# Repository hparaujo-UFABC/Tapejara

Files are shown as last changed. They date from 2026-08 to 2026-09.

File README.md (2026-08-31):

# Tapejara
## Open-source quadcopter drone for research and teaching

tapejaraProject03

[Primeiro Voo](https://youtu.be/oPYGQzMy-3I) do Tapejara 1.

🇧🇷
Projeto de um drone quadricóptero como plataforma de ensino e pesquisa.
O projeto da PCB foi realizado com a ferramenta EasyEDA Pro [https://easyeda.com/] e os primeiros protótipos foram fabricados na JLCPCB [https://jlcpcb.com/].
O Tapejara é um minidrone do tipo quadricóptero equipado com uma câmera OV2640 e sensores de IMU, barômetro e magnetômetro. Ele utiliza um microprocessador ESP32 para coletar dados dos sensores, calcular ações de controle e fornecer telemetria.
O drone pode ser controlado remotamente por meio de um aplicativo móvel.
O Tapejara foi projetado para servir como uma plataforma de pesquisa educacional para experimentação com firmware de voo, sistemas de controle e coleta de dados. Por esse motivo, a placa de circuito impresso (PCB) permite expansão via placa filha (*shield*), onde sensores adicionais podem ser instalados.
Vale mencionar que "Tapejara" é um gênero de pterossauro que viveu no Brasil durante o período Cretáceo.

🇺🇸
Design of a quadcopter drone as a teaching and research platform.
The PCB design was created using the EasyEDA Pro tool [https://easyeda.com/], and the initial prototypes were manufactured by JLCPCB [https://jlcpcb.com/].
The Tapejara is a quadcopter-style minidrone equipped with an OV2640 camera and IMU, barometer, and magnetometer sensors. It utilizes an ESP32 microprocessor to collect sensor data, calculate control actions, and provide telemetry.
The drone can be controlled remotely via a mobile app.
The Tapejara was designed to serve as an educational research platform for experimenting with flight firmware, control systems, and data collection. For this reason, the printed circuit board (PCB) allows for expansion via a daughterboard (shield) where additional sensors can be installed.
By the way, "Tapejara" is a genus of pterosaur that lived in Brazil during the Cretaceous period.

## ⚖️ Licença / License

Este é um projeto acadêmico híbrido (Hardware + Software) desenvolvido sob a organização `[Universidade Federal do ABC - UFABC]`. Para incentivar a inovação e facilitar parcerias com a indústria, o projeto utiliza um modelo de licenciamento amigável para uso comercial:

### 🇧🇷 Versão em Português

*   **Hardware (Esquemas, PCBs e Arquivos CAD):** Licenciado sob a [CERN Open Hardware Licence Version 2 – Weak Reciprocal](LICENSE-HARDWARE.md) (**CERN-OHL-W v2**).
    *   *O que isso significa:* Você pode integrar este hardware em produtos comerciais e sistemas proprietários fechados. No entanto, qualquer modificação, melhoria ou correção feita **diretamente nos arquivos de design da nossa placa** deve ser compartilhada publicamente sob a mesma licença.
*   **Software e Firmware:** Licenciado sob a [Apache License 2.0](LICENSE).
    *   *O que isso significa:* O código pode ser usado, modificado e distribuído livremente (inclusive comercialmente), oferecendo proteção explícita de patentes para os desenvolvedores e usuários.

---

### 🇺🇸 English Version

*   **Hardware (Schematics, PCBs, and CAD files):** Licensed under the [CERN Open Hardware Licence Version 2 – Weak Reciprocal](LICENSE-HARDWARE.md) (**CERN-OHL-W v2**).
    *   *What this means:* You are free to integrate this hardware into commercial products and proprietary closed systems. However, any modifications, improvements, or fixes made **directly to our board's design files** must be shared publicly under the same license.
*   **Software and Firmware:** Licensed under the [Apache License 2.0](LICENSE).
    *   *What this means:* The code can be freely used, modified, and distributed (including commercially), providing explicit patent protection for both developers and users.

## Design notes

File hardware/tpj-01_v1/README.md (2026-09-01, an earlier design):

🇧🇷
# Tapejara 1

Primeiro [voo](https://youtu.be/oPYGQzMy-3I) do Tapejara.

Veja a [documentação](./tapejaraBoard_v1.pdf) — Esquemático, layout da PCB e visualização 3D.

[Link](https://oshwlab.com/hparaujo.ufabc/project_sygmsikm?registerLang=en) do projeto no [OSHWLab](https://oshwlab.com/).

> Errata: A pinagem do conector da câmera OV2640 está espelhada: 1 <-> 24 | 24 <-> 1. Não tente conectar a câmera, pois isso causará um curto-circuito na PCB.
> Uma versão corrigida será disponibilizada em uma atualização futura (em breve).
> Todas as outras funcionalidades permanecem inalteradas. O protótipo foi testado em voo por linha de visada.

# Introdução ao projeto

O Tapejara tpj-01 é um micro-drone no estilo quadricóptero equipado com uma câmera OV2640 e sensores IMU, barômetro e magnetômetro. Ele utiliza um microprocessador ESP32 para coletar dados dos sensores, calcular as ações de controle e fornecer telemetria. O drone pode ser controlado remotamente por meio de um aplicativo móvel (atualmente em desenvolvimento).

O tpj-01 foi projetado para servir como uma plataforma de pesquisa educacional para experimentos com firmware de voo, sistemas de controle e coleta de dados. Por esse motivo, a placa de circuito impresso (PCB) permite expansão através de uma placa secundária (shield) onde sensores adicionais podem ser instalados.

A propósito, "Tapejara" é um gênero de pterossauro que viveu no Brasil durante o período Cretáceo.

# Componentes do projeto

* MCU: ESP32-S3 WROOM-1-N16R8
* Câmera OV2640
* IMU: MPU-6050
* Barômetro: BMP280
* Magnetômetro: QMC5883P
* Motores: coreless 7016 / 7020 / 8020 / 8520 (precisa lixar a PCB p/ encaixar o motor) : 2x CW + 2x CCW
* Diâmetro das hélices: 55 / 65 mm (2x CW + 2x CCW)
* Bateria: 1S (3.7V) | 500 mAh
* PCB (X-Frame):
  * Material: FR-4
  * Cor: Verde
  * Espessura: 1.2 mm
* Controle remoto via aplicativo móvel e Wi-Fi

# Descrição do hardware

Este projeto consiste nas seguintes partes:

* O MCU para controle de voo (PID + PWM), coleta de dados dos sensores e telemetria;
* Gerenciamento de energia: a fonte de energia primária do sistema é uma bateria 1S que alimenta os motores diretamente. Um regulador Buck-Boost gera um valor estável de 3.3V para o MCU e os sensores. A câmera também precisa de reguladores LDO para 1.3V e 2.8V, ambos derivados do regulador de 3.3V. A bateria possui proteção contra inversão de polaridade.
* USB/OTG: uma porta micro USB tipo C é usada para upload de firmware e alimentação (durante a programação do drone). Ela possui proteção contra ESD (Descarga Eletrostática).
* PWM: os 4 motores são controlados via sinais PWM gerados no MCU que chaveiam 4 FETs NMOS de potência.
* Sinalização: 4 LEDs podem ser usados para fornecer feedback visual ao usuário. Durante o voo, eles são mantidos acesos para indicação de direção (2 LEDs vermelhos estão posicionados no lado esquerdo do frame e 2 LEDs verdes no lado direito).
* Expansão por Shield: é possível projetar uma placa secundária para expansão de sensores/processamento. A placa principal fornece a tensão da bateria, 3.3V, conexão de aterramento (GND) e 4 pinos de E/S do ESP32 (2 da conexão I²C dos sensores e 2 pinos adicionais).

A própria placa de circuito impresso (PCB) foi projetada em uma configuração em "X" para suportar os motores diretamente, eliminando assim a necessidade de suportes adicionais impressos em 3D. O design é autocontido. A bateria e a câmera devem ser fixadas à placa usando qualquer meio disponível. Para a câmera, existem dois furos na parte frontal do drone que podem ser úteis.

# Processos de montagem

A placa de circuito impresso (PCB) é autocontida. Basta encaixar os quatro motores sob pressão nos devidos lugares (seguindo as marcações impressas na placa) e montar a câmera e a bateria.

O firmware pode ser enviado através da porta USB usando a Arduino IDE. A taxa de transmissão serial (baud rate) é 115200. Para usar a Arduino IDE na programação, selecione esta placa: ESP32-S3-USB-OTG.

Após o upload do firmware, o drone deve ser configurado usando o aplicativo de controle remoto (RC).

# Exibição do produto final

Visualização 3D da PCB (superior e inferior).
3D_Tapejara_brd_v1_Top
3D_Tapejara_brd_v1_Bott

Peso da PCB de apenas 12g.
drone32g

Peso do drone montado de apenas 32.36g.
weightAssembl

Imagem final.
tapejaraAssembled

---

🇺🇸
# Tapejara 1
First [flight](https://youtu.be/oPYGQzMy-3I) of Tapejara.

See the [documentation](./tapejaraBoard_v1.pdf) -- Schematic, PCB layout and 3D view.

Project [Link](https://oshwlab.com/hparaujo.ufabc/project_sygmsikm?registerLang=en) on [OSHWLab](https://oshwlab.com/).

>Errata: The pinout of the OV2640 camera connector is mirrored: 1 &lt;-&gt; 24 | 24 &lt;-&gt; 1. Do not try to connect the camera or it will cause a short-circuit in the PCB.
>A corrected version will be provided in a future update (coming soon).
>All other functionalities remain unchanged. The prototype has been flight-tested via line-of-sight.

# Project introduction
The Tapejara tpj-01 is a quadcopter-style micro-drone equipped with an OV2640 camera and IMU, barometer, and magnetometer sensors. It utilizes an ESP32 microprocessor to collect sensor data, calculate control actions, and provide telemetry.
The drone can be controlled remotely via a mobile app (currently under development).
The tpj-01 was designed to serve as an educational research platform for experimenting with flight firmware, control systems, and data collection. For this reason, the printed circuit board (PCB) allows for expansion via a daughterboard (shield) where additional sensors can be installed.
By the way,  "Tapejara" is a genus of pterosaur that lived in Brazil during the Cretaceous period.

# Project Components
* MCU: ESP32-S3 WROOM-1-N16R8
* OV2640 camera
* IMU: MPU-6050
* Barometer: BMP280
* Magnetometer: QMC5883P
* Rotors: 7016 / 7020 / 8020 / 8520 coreless motors (requires sanding the PCB to accommodate the motor): 2x CW + 2x CCW
* Propellers Diameter: 55 / 65 mm (2x CW + 2x CCW)
* Battery: 1S (3.7V) | 500 mAh
* PCB (X-Frame):
    * Material: FR-4
    * Color: Green
    * Thickness: 1.2 mm
* Remote control via Mobile App and Wi-Fi

# Hardware description
This project consists of the following parts:
* The MCU for flight control (PID + PWM), data sensor collection and telemetry;
* Power management: the primary energy source for the system is an 1S battery that supply the rotors directly. A Buck-Boost regulator generates a stable 3.3V for the MCU and the sensors. The camera also needs LDO regulators for 1.3V and 2.8V, both derived from the 3.3V regulator. The battery is protected against polarity inversion.
* USB/OTG: a type-C micro USB port is used for firmware upload and power supply (during the drone programming). It is protected against ESD (ElectroStatic Discharge).
* PWM: the 4 rotors are controlled via PWM signals generated at the MCU that switch 4 power NMOS FETs.
* Sinalization: 4 LEDs can be used to provide visual feedback to the user. During flight, they are kept on for direction indication (2 red LEDs are positioned at the left-side of the frame and 2 green LEDs at the right-side).
* Shield expansion: it is possible to design a daughterboard for sensor/processing expansion. The main board provides the battery voltage, 3.3V, ground (GND) connection, and 4 ESP32 I/O pins (2 from the I²C sensors connection and 2 additional pins).

The printed circuit board (PCB) itself was designed with an "X" configuration to support the rotors directly, thereby eliminating the need for additional 3D-printed mounts. The design is self-contained.
The battery and camera must be secured to the board using any available means. For the camera, there are two holes on the front of the drone that may be useful.

# Assembling processes
The printed circuit board (PCB) is self-contained. Simply press-fit the four rotors into place (following the markings printed on the board) and mount the camera and battery.
The firmware can be uploaded via the USB port using the Arduino IDE. The serial baud rate is 115200.
To use the Arduino IDE for programming, select this board: ESP32-S3-USB-OTG.
After uploading the firmware, the drone must be configured using the remote control (RC) app.

# Finished product display
3D view of the PCB (top and bottom).

3D_Tapejara_brd_v1_Top

3D_Tapejara_brd_v1_Bott

PCB weight of only 12g.

drone32g

Assembled Drone weight of only 32.36g.

weightAssembl

Final image.

tapejaraAssembled

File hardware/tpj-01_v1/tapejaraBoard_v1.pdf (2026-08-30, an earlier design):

# TPJ-01

# Rotors: coreless 8520 (2x CW + 2x CCW)

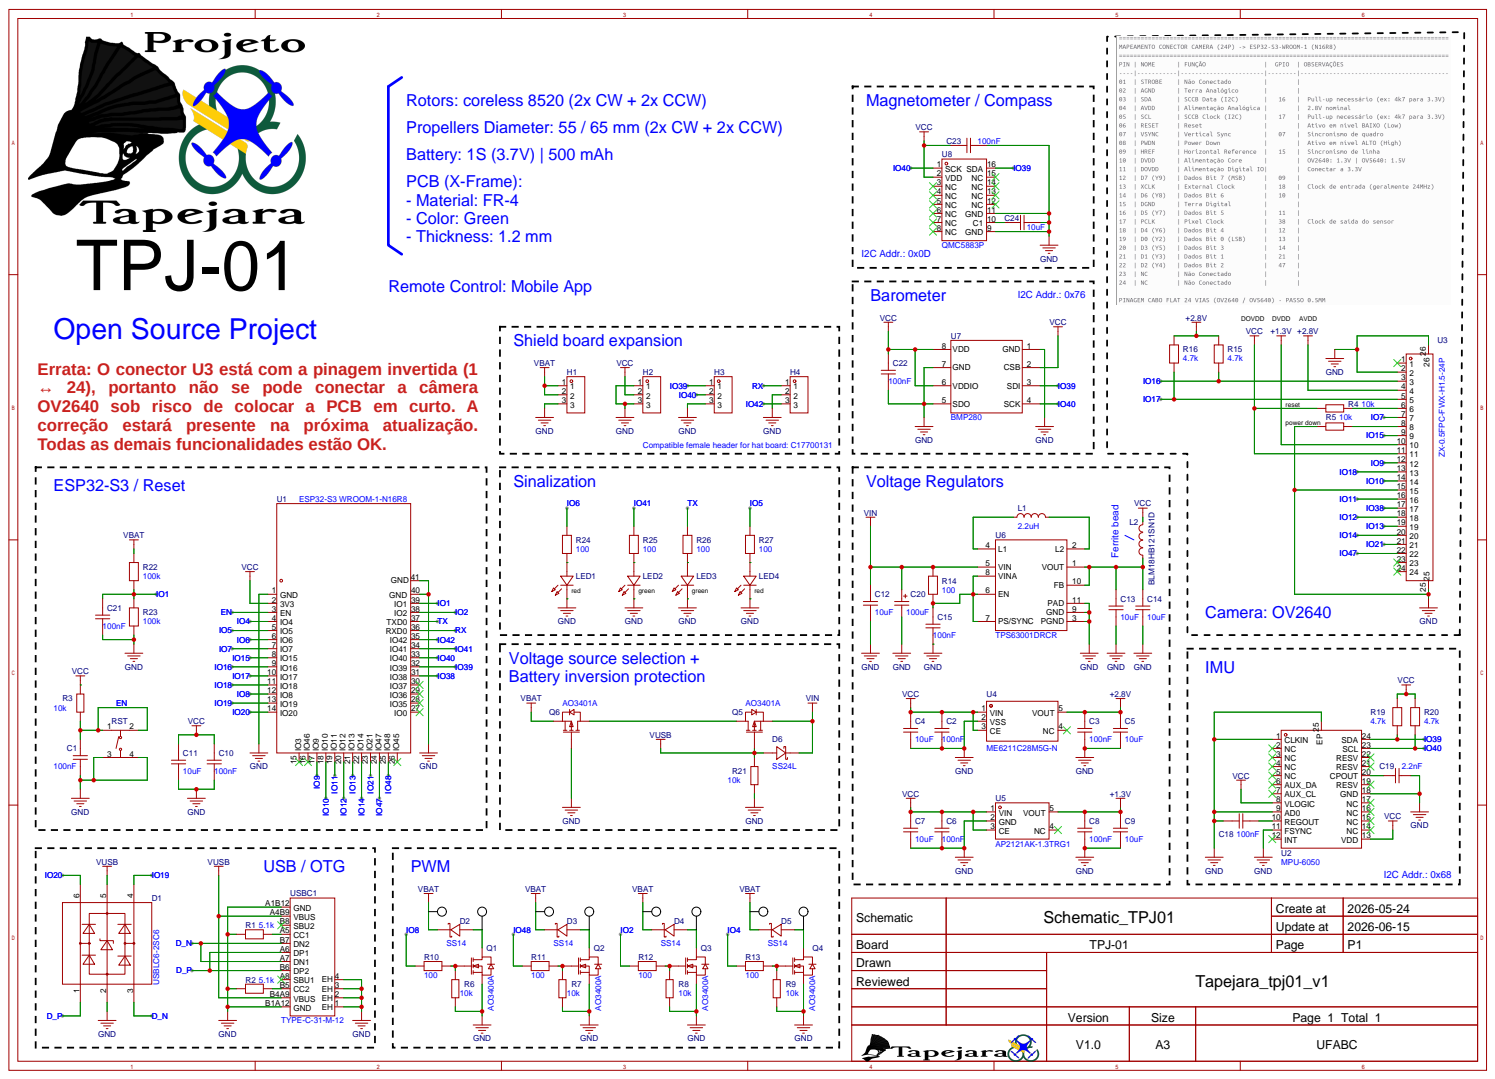
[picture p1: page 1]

Propellers Diameter: 55 / 65 mm (2x CW + 2x CCW)
Battery: 1S (3.7V) | 500 mAh
PCB (X-Frame):
- Material: FR-4
- Color: Green
- Thickness: 1.2 mm

C1 10 GND 11 NC 12 NC 13 NC 14 NC 15 SDA 16

Remote Control: Mobile App

Errata: O conector U3 está com a pinagem invertida (1
↔ 24), portanto não se pode conectar a câmera
OV2640 sob risco de colocar a PCB em curto. A
correção estará presente na próxima atualização.
Todas as demais funcionalidades estão OK.
ESP32-S3 / Reset

GND
Compatible female header for hat board: C17700131

Schematic | Schematic_TPJ01 | Create at | 2026-05-24

Update at | 2026-06-15

Board | TPJ-01 | Page | P1
Drawn | | Tapejara_tpj01_v1
Reviewed

Version | Size | Page 1 Total 1
V1.0 | A3 | UFABC

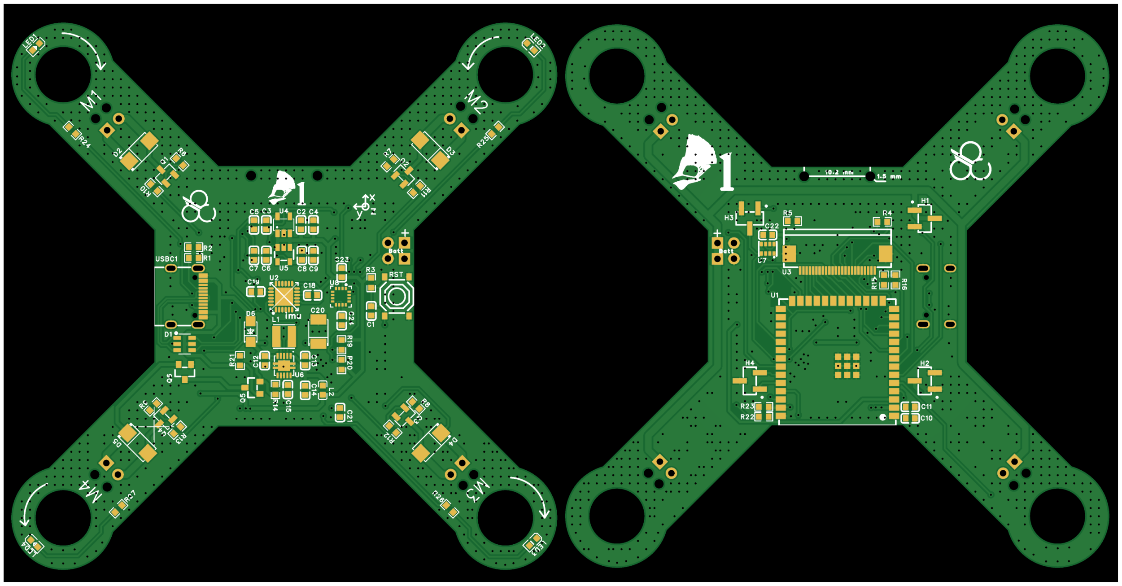
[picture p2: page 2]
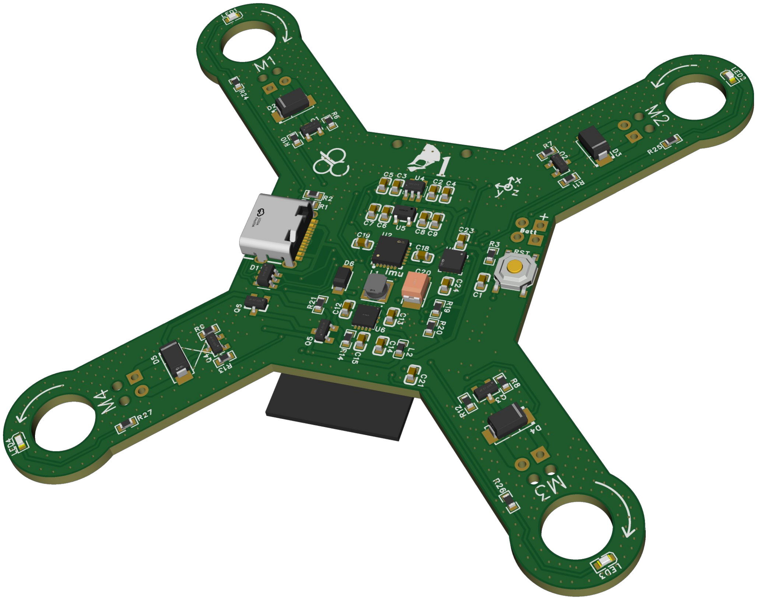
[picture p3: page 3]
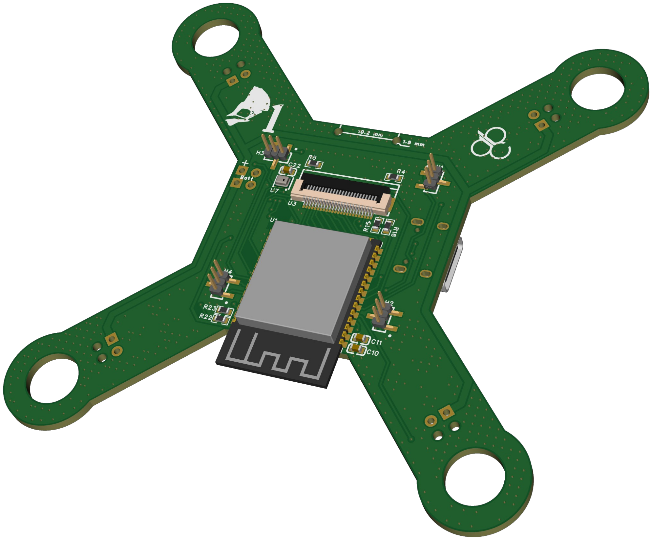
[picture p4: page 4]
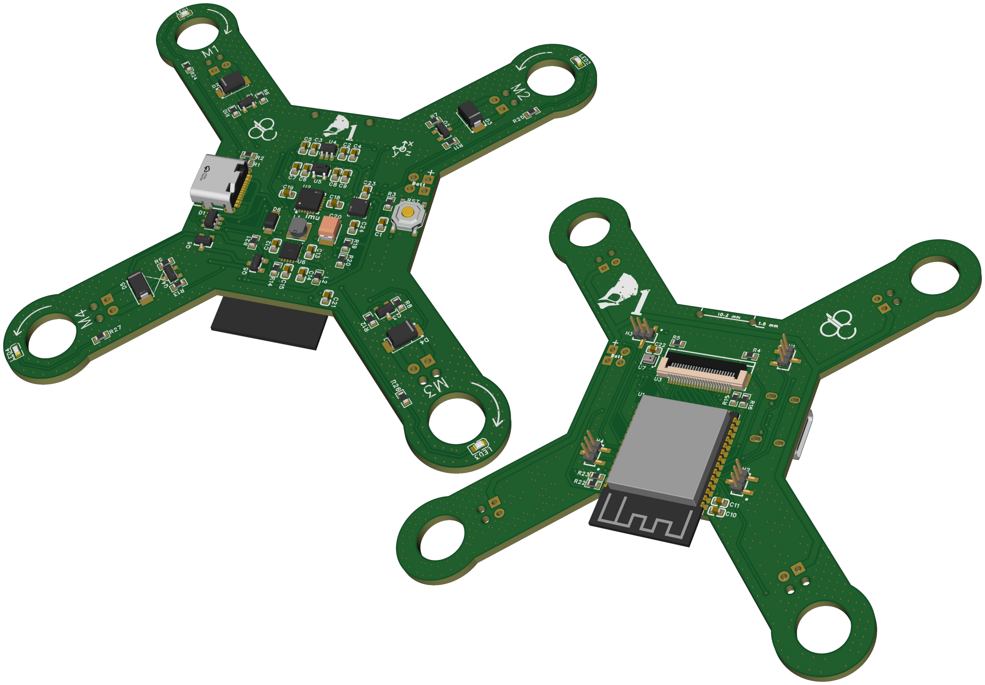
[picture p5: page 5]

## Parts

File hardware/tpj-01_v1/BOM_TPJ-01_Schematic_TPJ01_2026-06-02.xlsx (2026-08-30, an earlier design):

No. | Quantity | Comment | Designator | Footprint | Value | Manufacturer Part | Manufacturer | Supplier Part | Supplier
1 | 11 | 100nF | C1,C2,C3,C6,C8,C10,C15,C18,C21,C22,C23 | C0603 | 100nF | CC0603KRX7R7BB104 | YAGEO(国巨) | C108079 | LCSC
2 | 9 | 10uF | C4,C5,C7,C9,C11,C12,C13,C14,C24 | C0603 | 10uF | GRM188Z71A106MA73D | muRata(村田) | C237435 | LCSC
3 | 1 | 2.2nF | C19 | C0603 | 2.2nF | CC0603KRX7R9BB222 | YAGEO(国巨) | C107082 | LCSC
4 | 1 | 100uF | C20 | CASE-B_3528 | 100uF | TAJB107M010RNJ | Kyocera AVX | C7196 | LCSC
5 | 1 | USBLC6-2SC6 | D1 | SOT-23-6_L2.9-W1.6-P0.95-LS2.8-BL |  | USBLC6-2SC6 | ST(意法半导体) | C7519 | LCSC
6 | 4 | SS14 | D2,D3,D4,D5 | SMA_L4.3-W2.6-LS5.2-RD |  | SS14 | onsemi(安森美) | C83852 | LCSC
7 | 1 | SS24L | D6 | SOD-123FL_L2.8-W1.8-LS3.7-R-RD |  | SS24L | Hottech(合科泰) | C2827931 | LCSC
8 | 4 | B12720520-3PB0514-H10C43 | H1,H2,H3,H4 | HDR-SMD_3P-P1.27-V-M-LS4.2_X1311WVS-R2 |  | B12720520-3PB0514-H10C43 | HMTCONN(华明通) | C51823023 | LCSC
9 | 1 | 2.2uH | L1 | IND-SMD_L3.0-W3.0_SMNR3015 | 2.2uH | ANR3015T2R2M | APV(爱普微) | C6364793 | LCSC
10 | 1 | BLM18HB121SN1D | L2 | L0603 |  | BLM18HB121SN1D | muRata(村田) | C14710 | LCSC
11 | 2 | XL-1608SURC-06 | LED1,LED4 | LED0603-RD_RED |  | XL-1608SURC-06 | XINGLIGHT(成兴光) | C965799 | LCSC
12 | 2 | 19-219/GHC-YR2T1B5Y/3T | LED2,LED3 | LED-SMD_L1.6-W0.8_19-219-GHC-YR2T1B5Y-3T |  | 19-219/GHC-YR2T1B5Y/3T | EVERLIGHT(亿光) | C2994781 | LCSC
13 | 4 | AO3400A | Q1,Q2,Q3,Q4 | SOT-23-3_L2.9-W1.3-P1.90-LS2.4-BR |  | AO3400A | AOS | C20917 | LCSC
14 | 2 | AO3401A | Q5,Q6 | SOT-23_L2.9-W1.3-P1.90-LS2.4-BR |  | AO3401A | AOS | C15127 | LCSC
15 | 2 | 5.1kΩ | R1,R2 | R0603 | 5.1kΩ | FRC0603F5101TS | FOJAN(富捷) | C2907044 | LCSC
16 | 8 | 10kΩ | R3,R4,R5,R6,R7,R8,R9,R21 | R0603 | 10kΩ | RC0603FR-0710KL | YAGEO(国巨) | C98220 | LCSC
17 | 9 | 100Ω | R10,R11,R12,R13,R14,R24,R25,R26,R27 | R0603 | 100Ω | FRC0603F1000TS | FOJAN(富捷) | C2906981 | LCSC
18 | 4 | 4.7kΩ | R15,R16,R19,R20 | R0603 | 4.7kΩ | FRC0603F4701TS | FOJAN(富捷) | C2907034 | LCSC
19 | 2 | 100kΩ | R22,R23 | R0603 | 100kΩ | FRC0603F1003TS | FOJAN(富捷) | C2906980 | LCSC
20 | 1 | TS-1187A-B-A-B | RST | SW-SMD_4P-L5.1-W5.1-P3.70-LS6.5-TL_H1.5 |  | TS-1187A-B-A-B | XKB Connection(中国星坤) | C318884 | LCSC
21 | 1 | ESP32-S3 WROOM-1-N16R8 | U1 | WIRELM-SMD_ESP32-S3-WROOM-1 | ESP32-S3 WROOM-1-N16R8 | ESP32-S3-WROOM-1-N16R8 | ESPRESSIF(乐鑫) |  | LCSC
22 | 1 | MPU-6050 | U2 | QFN-24_L4.0-W4.0-P0.50-BL-EP2.7 |  | MPU-6050 | TDK InvenSense(应美盛) | C24112 | LCSC
23 | 1 | ZX-0.5FPC-FWX-H1.5-24P | U3 | FPC-SMD_24P-P0.50_ZX-0.5FPC-FWX-H1.5-24P |  | ZX-0.5FPC-FWX-H1.5-24P | Megastar(兆星) | C7544628 | LCSC
24 | 1 | ME6211C28M5G-N | U4 | SOT-23-5_L3.0-W1.7-P0.95-LS2.8-BR |  | ME6211C28M5G-N | MICRONE(南京微盟) | C53099 | LCSC
25 | 1 | AP2121AK-1.3TRG1 | U5 | SOT-23-5_L2.9-W1.6-P0.95-LS2.8-BL |  | AP2121AK-1.3TRG1 | DIODES(美台) | C6124322 | LCSC
26 | 1 | TPS63001DRCR | U6 | VSON-10_L3.0-W3.0-P0.50-TL-EP_TPS62410DRCR |  | TPS63001DRCR | TI(德州仪器) | C28060 | LCSC
27 | 1 | BMP280 | U7 | LGA-8_L2.5-W2.0-P0.65_AMP6127 |  | BMP280 | Bosch(博世) | C83291 | LCSC
28 | 1 | QMC5883P | U8 | LGA-16_L3.0-W3.0-P0.50-BL_SQ |  | QMC5883P | QST(上海矽睿) | C2847467 | LCSC
29 | 1 | TYPE-C-31-M-12 | USBC1 | USB-C_SMD-TYPE-C-31-M-12_1 |  | TYPE-C-31-M-12 | 韩国韩荣 | C165948 | LCSC

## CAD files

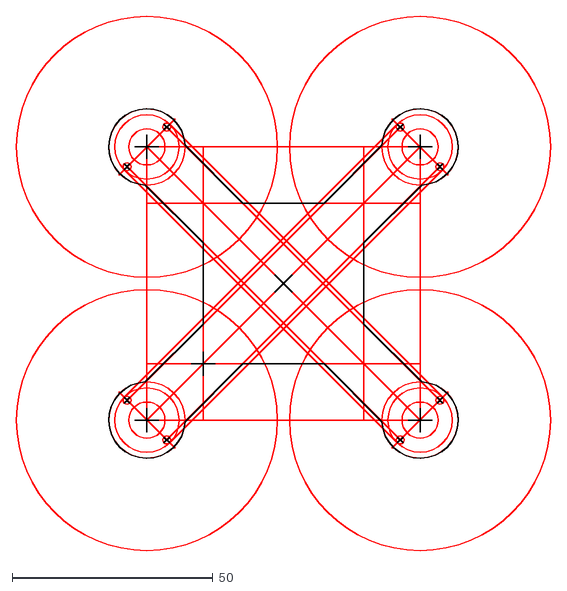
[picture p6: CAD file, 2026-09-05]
hardware/tpj-01_v2/tapejaraFrameX_65AroMaior.dxf
133.0 x 133.0

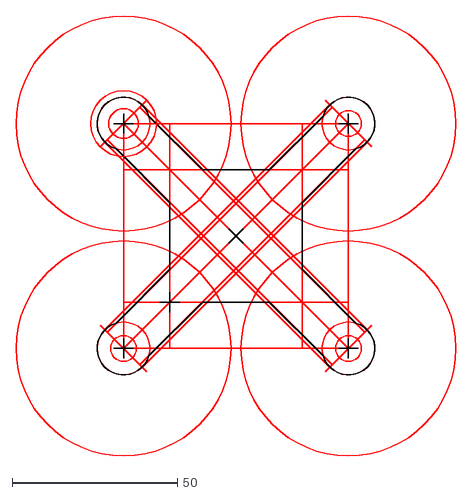
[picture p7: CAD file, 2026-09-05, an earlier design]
hardware/tpj-01_v1/tapejaraFrameX_65.dxf
133.0 x 133.0

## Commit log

2026-08-31 Movendo p/ tpj-01_v1
    [BOM_TPJ-01_Schematic_TPJ01_2026-06-02.xlsx, PickAndPlace_PCB_TPJ01_2026-06-02.xlsx]
2026-09-01 Update README with documentation and errata details
    Added project link and errata information for the OV2640 camera connector.
2026-09-05 Add files via upload
    Arquivo CAD do chassi
    [tapejaraFrameX_65.dxf]
